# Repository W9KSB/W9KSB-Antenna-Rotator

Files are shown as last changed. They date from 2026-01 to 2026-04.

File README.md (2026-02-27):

# 🚀 Introducing the W9KSB Antenna Rotator

Movement Demo (https://www.youtube.com/watch?v=zZoIDCE3QLc)

(Video Above, Click to Play)

## About This Project (Overview)

This project is not a polished commercial product. It is a real-world, homebrew build that grew out of practical needs, experimentation, and a lot of tinkering. This project is provided for educational and hobby purposes only. Use at your own risk. I am not responsible for any damage resulting from construction or use.

The W9KSB Antenna Rotator exists because I wanted a reliable way to automate satellite tracking and reception from home without expensive commercial hardware. Along the way, the project evolved through trial, error, discussion, and learning — exactly how most good DIY projects do.

Everything here is shared **as-is**.  
There are **no warranties, guarantees, or promises of fitness** for any particular purpose.  
Hardware, software, and configurations may change over time, and what works in my environment may require adjustment in yours.

This GitHub repository hosts the bulk of the project, while my website provides detailed narrative posts, explanations, photos, and updates:

👉 https://www.w9ksb.com/

## Intent and Philosophy

- Document the build honestly — including decisions, tradeoffs, and limitations  
- Provide a clear starting point for others  
- Encourage experimentation, modification, and improvement  
- Share openly with the ham radio, SDR, and maker communities  

This is an off‑hours hobby project.  
Support is not guaranteed, and responses may be slow.  
Pull requests and respectful discussion are always welcome.

*(Disclaimer: This all needs updates I’m sure and I will be making many more edits. This is the literal first iteration of all of this, but I welcome feedback!)*

Main Rotator Image

Satellite passes are short. Winter is cold. Holding a heavy Yagi pointed at the sky for 12–15 minutes while trying to decode SSTV or weather images gets old fast.

This rotator was built to solve exactly that.

This project is a fully DIY AZ/EL antenna rotator powered by a Raspberry Pi 5, designed to integrate well with satellite reception and SSTV decoding workflows. The Pi runs everything — including SDR processing — so you can place the rotator outside, and the only thing entering the house is a short SMA cable.

Everything runs headless on a Pi 5 and integrates with:

- **Gpredict**
- **SatDump**
- **Hamlib rotctld**
- **RTL-SDR (optional)**

It can also run **SSTV decoding**, **NOAA/Meteor weather imaging**, and other tasks directly onboard.

---

# 🎯 Goals

- Fully automate satellite tracking
- Avoid holding a Yagi in freezing weather
- Decode signals while the rotator tracks passes automatically
- Keep the software modular and simple
- Use off-the-shelf parts wherever possible
- Document the entire build so others can replicate or improve it

---

# 🧰 Hardware Overview

## Core Components

- Raspberry Pi 5  
- Adafruit DC & Stepper Motor HAT  
- Two worm-gear DC motors (AZ + EL)  
- AS5600 absolute magnetic encoders  
- PETG 3D-printed body  
- Tripod mount  
- Optional RTL-SDR v4 for on-board reception  

### Wiring Diagram

Wiring Diagram

Encoders:
- One on hardware I²C bus 1  
- One on software I²C bus 3 via bit-banged GPIO  

Motors:
- Driven by Motor HAT  
- Powered by a linear 12V supply  
- Pi is powered by a buck converter  

---

# 🧬 Software Overview

The software consists of several Python modules:

| File | Purpose |
|---|---|
| **hamlib_server.py** | TCP server compatible with Hamlib/rotctld |
| **controller.py** | Brain of system — control loop, limits, homing |
| **movement.py** | Motor control via Motor HAT |
| **position.py** | AS5600 encoder interface |
| **config.py** | Central configuration file |
| **rotator_cal.json** | Stores calibration offsets |
| **manual.py** | Manual testing & jogging tool |

---

# 📸 Build Photos 

### Tripod Mount





### Rotator Body

Top

### Elevation Assembly

EL Hub
EL Side

### Bottom Access

Bottom

---

# 🛒 Parts List

## Core Electronics

| Product | Qty | Price | Link |
|---|-----|---|---|
| Raspberry Pi 5 | 1 | $91.00 | https://amzn.to/4rhhwjt |
| Adafruit Motor HAT | 1 | $29.79 | https://amzn.to/4t51I58 |
| Pin headers | 1 | $3.99 | https://amzn.to/4sYME8Z |
| AS5600 Encoders (4pk) | 1 | $9.99 | https://amzn.to/46frJ7J |
| Jumper wires | 1 | $6.98 | https://amzn.to/3O4QMnJ |

## Motors & Mechanics

| Product | Qty | Price | Link |
|---|-----|---|---|
| Worm gear motors (12v, 6rpm) | 2 | $9.37 | https://s.click.aliexpress.com/e/_mtrPuZF |
| Hyper Hub 1310 (6mm) | 2 | $7.99 | https://www.servocity.com/1310-series-hyper-hub-6mm-d-bore/ |
| Roller bearing | 1 | $7.98 | https://amzn.to/4r6E8D8 |
| Heat-set inserts | 1 | $15.99 | https://amzn.to/460NZ5c |
| M3 screws | 1 | $6.99 | https://amzn.to/4r5rLHe |

## Structural

| Product | Qty | Price | Link |
|---|-----|---|---|
| Tripod stand | 1 | $37.99 | https://amzn.to/4t0KGF3 |
| PETG filament | 2 | $14.43 | https://amzn.to/4bfPoIE |
| Baseball donut weight | 1–2 | $7.99 | https://amzn.to/4bmx7JI |

## Power & Wiring

| Product | Qty | Price | Link |
|---|-----|---|---|
| Linear PSU | 1 | $20 | https://amzn.to/49Xoov6 |
| DC pigtail | 1 | $8.99 | https://amzn.to/4bp9bpf |
| 12→5V buck | 1 | $9.59 | https://amzn.to/3ZuMDfl |
| 12V buck | 1 | $7.99 | https://amzn.to/49IAQjy |
| 28 AWG wire | 1 | $5.99 | https://amzn.to/3NwWkYa |

## Optional Onboard SDR

| Product | Qty | Price | Link |
|---|-----|---|---|
| RTL-SDR v4 | 1 | $39.99 | https://amzn.to/4k0bTU7 |
| SMA cable | 1 | $6.99 | https://amzn.to/45tG7sN |
| SMA bulkhead | 1 | $5.98 | https://amzn.to/49TQMhJ |

*These are the parts I ordered and used. Links below are affiliate links and I may earn a small commission on the sale at no additional cost to you.*
---

# 🧠 Software Architecture Deep Dive

## 📡 hamlib_server.py

- Implements TCP rotctld protocol  
- Talks to Gpredict & SatDump  
- On disconnect → returns AZ & EL to home  

## 🧮 controller.py

Handles:

- Control loop  
- Shortest-path AZ logic  
- Elevation limit enforcement  
- Homing  
- Arrival detection  

## ⚙ movement.py

- Motor HAT interface  
- Speed control  
- Direction handling  

## 🧭 position.py

- Reads AS5600 encoders  
- Bus 1 (hardware) + Bus 3 (bit‑banged)  
- Converts raw readings into degrees  

## 📝 config.py

- Motor speeds  
- Pins  
- I²C bus mappings  
- Limits  
- Thresholds  

## 🎯 rotator_cal.json

Stores offsets:

- **Elevation offset** is usually the only one you need  
- **Azimuth home** auto-sets at startup  
- AZ offset still supported for customization (v1 feature)  

## 🎛 manual.py

A simple tool for:

- Motor jogging  
- Testing direction  
- Verifying encoders  
- Manual positioning  

---

# 🏃 Running the Code

## Install prerequisites

```bash
sudo apt update && sudo apt upgrade -y
sudo apt install -y python3 python3-pip git i2c-tools adafruit-circuitpython-motorkit
```

## Enable I²C

```bash
sudo raspi-config
```

Enable I²C → Reboot.

## Enable Bit-Banged I²C (Bus 3)

Edit:

```bash
sudo nano /boot/config.txt
```

Add:

```
dtoverlay=i2c-gpio,bus=3,i2c_gpio_sda=24,i2c_gpio_scl=25
```

Reboot.

---

## Clone the repo

```bash
git clone https://github.com/W9KSB/W9KSB-Antenna-Rotator.git
cd W9KSB-Antenna-Rotator
```

---

## Run manually

```bash
sudo python3 -u hamlib_server.py
```

---

## Install as system service

Create:

```bash
sudo nano /etc/systemd/system/antenna-rotator.service
```

Paste:

```ini
[Unit]
Description=W9KSB Antenna Rotator Server
After=network.target

[Service]
ExecStart=/usr/bin/python3 -u /home/pi/W9KSB-Antenna-Rotator/hamlib_server.py
WorkingDirectory=/home/pi/W9KSB-Antenna-Rotator
StandardOutput=inherit
StandardError=inherit
Restart=always
User=root

[Install]
WantedBy=multi-user.target
```

Enable:

```bash
sudo systemctl daemon-reload
sudo systemctl enable antenna-rotator.service
sudo systemctl start antenna-rotator.service
```

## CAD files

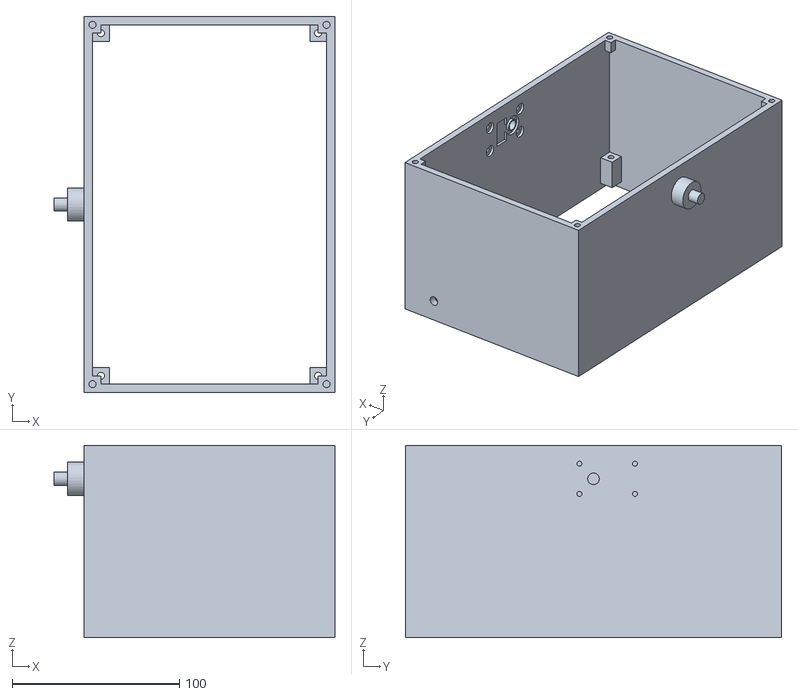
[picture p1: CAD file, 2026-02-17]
STL Files/Main Body.stl
168.0 x 225.0 x 115.0

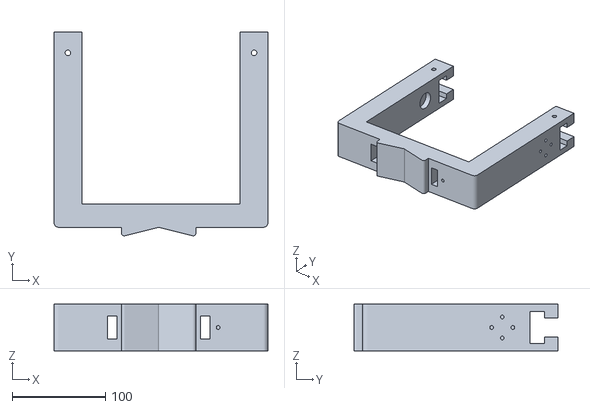
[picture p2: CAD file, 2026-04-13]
STL Files/Swing Arm With Antenna Mount Hole.stl
230.0 x 218.9 x 50.0

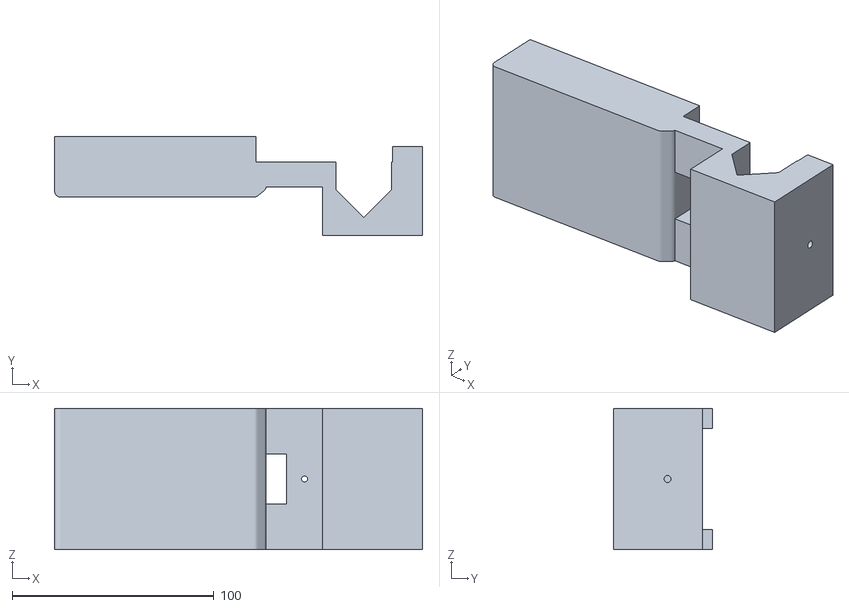
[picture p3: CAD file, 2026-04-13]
STL Files/Antenna Offset Mount - 45 Rotated.stl
182.5 x 49.0 x 70.0

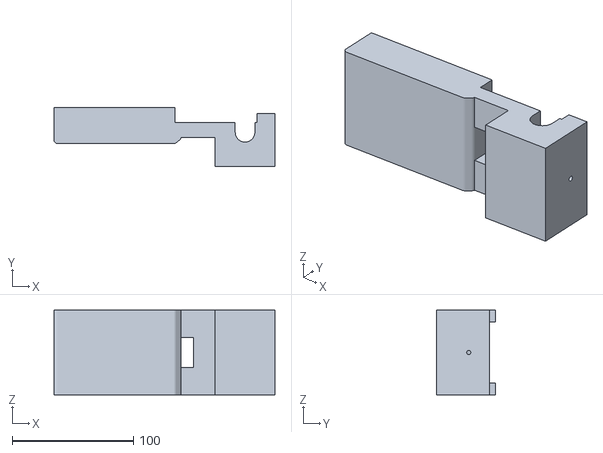
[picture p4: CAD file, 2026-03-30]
STL Files/ARRL Antenna Offset Mount.stl
182.5 x 49.0 x 70.0

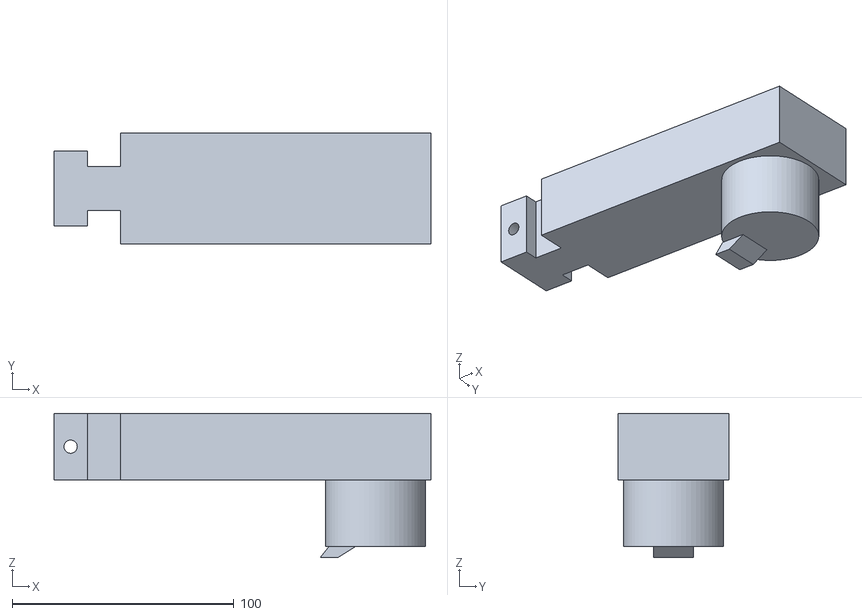
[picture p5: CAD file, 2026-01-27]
STL Files/Counterbalance Arm.stl
170.0 x 50.0 x 65.0

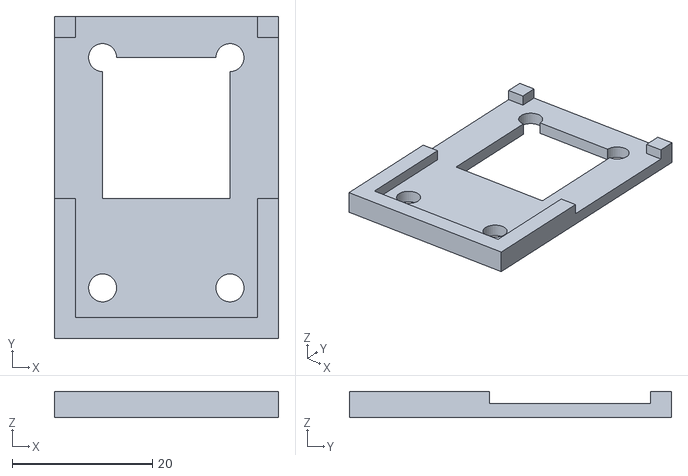
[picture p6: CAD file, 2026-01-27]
STL Files/Encoder Lid.stl
32.0 x 46.0 x 3.75

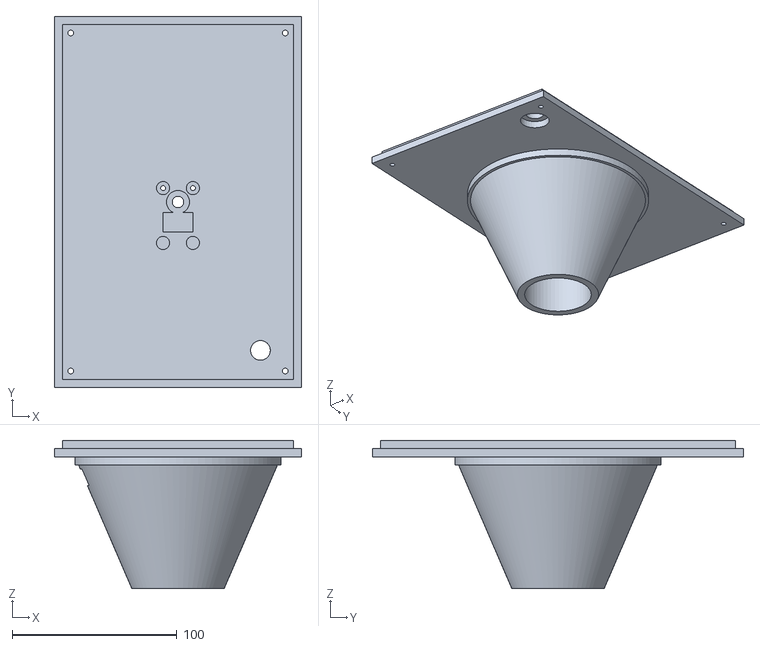
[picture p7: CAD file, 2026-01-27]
STL Files/Tripod Base Plate.stl
150.0 x 225.0 x 90.0

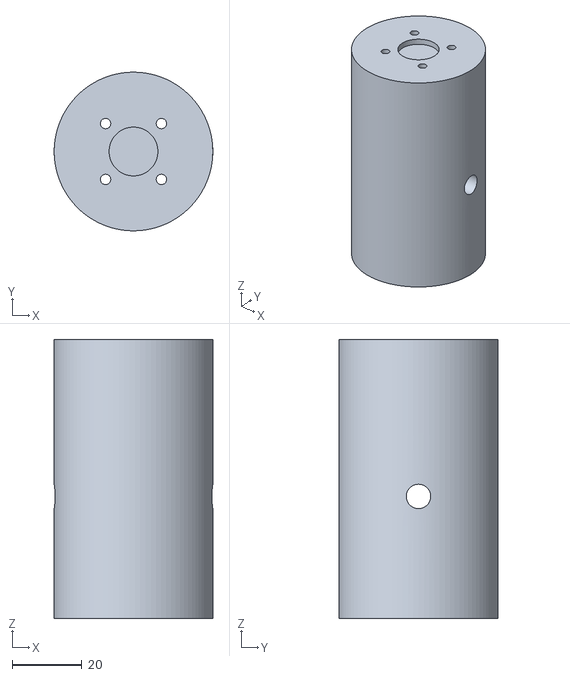
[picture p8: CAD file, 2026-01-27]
STL Files/Tripod Mount.stl
45.5 x 45.5 x 80.0

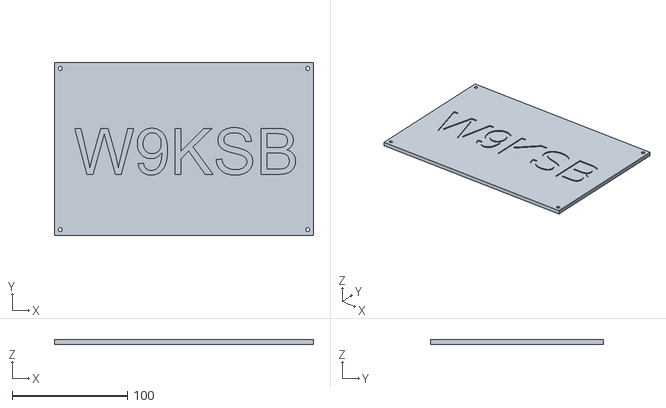
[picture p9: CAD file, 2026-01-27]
STL Files/Top Body Lid.stl
225.0 x 150.0 x 4.00

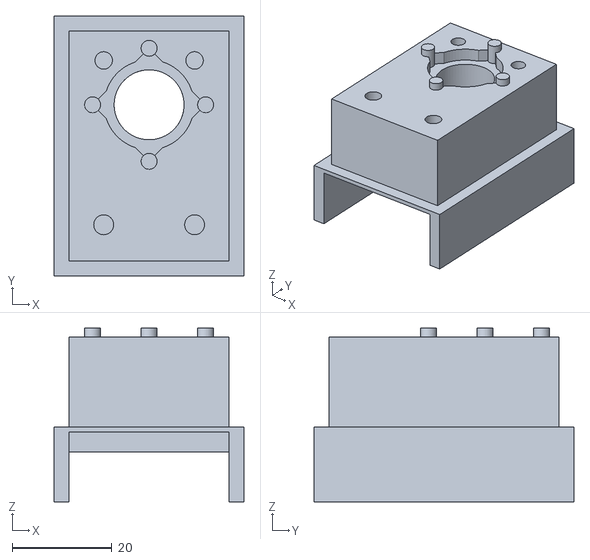
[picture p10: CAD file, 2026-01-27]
STL Files/Encoder Mount.stl
38.0 x 52.0 x 34.8

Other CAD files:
STL Files/3-4in Square Tube Antenna Offset Mount.stl
STL Files/Swing Arm - Adjusted for Counterbalance Arms.stl

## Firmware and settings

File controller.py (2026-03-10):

# controller.py
import time
import threading
import atexit

import config
import position
import movement

from Adafruit_MotorHAT import Adafruit_MotorHAT


def clamp(x, lo, hi):
    return max(lo, min(hi, float(x)))


class RotatorController:
    """
    Owns hardware and runs a background control loop.
    Exposes:
      - set_target(az_deg, el_deg)
      - get_position() -> (az_deg, el_deg)
      - stop()
    """

    def __init__(self, debug=False):
        self.debug = debug

        # Calibration
        self.cal = config.load_cal()

        # Motors
        self.mh = movement.init_motorhat()
        self.motor_az = self.mh.getMotor(1)
        self.motor_el = self.mh.getMotor(2)

        # Encoders
        self.enc_az = position.AS5600(config.ENCODER1_BUS, name="E1")
        self.enc_el = position.AS5600(config.ENCODER2_BUS, name="E2")
        self.az_tracker = position.UnwrappedAngle(self.enc_az)

        # State
        self._lock = threading.Lock()
        self._target_az = None  # physical 0..360
        self._target_el = None  # physical 0..90
        self._stop_requested = False

        self._cur_az_phys = 0.0
        self._cur_el_phys = 0.0
        self._cur_el_raw = 0.0  # raw AS5600 degrees (0..360)

        # Arrival reporting (print once per target)
        self._arrived_reported = False
        self._last_arrival_target = None  # (az, el)

        self._thread = None
        self._running = False

        # ----------------------------
        # EL control: breakaway search + approach slow + stall re-kick
        # ----------------------------
        self._el_dir_change_settle_s = float(getattr(config, "EL_DIR_CHANGE_SETTLE_S", 0.25))

        # Movement detection (raw degrees)
        self._el_move_thresh_deg = float(getattr(config, "EL_MOVE_THRESH_DEG", 0.25))
        self._el_move_window_s = float(getattr(config, "EL_MOVE_WINDOW_S", 0.30))

        # Stall detection (no meaningful movement while commanding)
        self._el_stall_time_s = float(getattr(config, "EL_STALL_TIME_S", 0.45))

        # Breakaway search (UP)
        self._el_up_bk_start = int(getattr(config, "EL_UP_BREAKAWAY_START_SPEED", 150))
        self._el_up_bk_step = int(getattr(config, "EL_UP_BREAKAWAY_STEP_SPEED", 25))
        self._el_up_bk_max = int(getattr(config, "EL_UP_BREAKAWAY_MAX_SPEED", 255))
        self._el_up_bk_interval_s = float(getattr(config, "EL_UP_BREAKAWAY_INTERVAL_S", 0.30))

        # Breakaway search (DOWN)
        self._el_down_bk_start = int(getattr(config, "EL_DOWN_BREAKAWAY_START_SPEED", 150))
        self._el_down_bk_step = int(getattr(config, "EL_DOWN_BREAKAWAY_STEP_SPEED", 25))
        self._el_down_bk_max = int(getattr(config, "EL_DOWN_BREAKAWAY_MAX_SPEED", 255))
        self._el_down_bk_interval_s = float(getattr(config, "EL_DOWN_BREAKAWAY_INTERVAL_S", 0.30))

        # Approach/creep windows
        self._el_approach_window_deg = float(getattr(config, "EL_APPROACH_WINDOW_DEG", 8.0))
        self._el_creep_window_deg = float(getattr(config, "EL_CREEP_WINDOW_DEG", 2.5))

        # Fixed approach/creep speeds
        self._el_approach_speed = int(getattr(config, "EL_APPROACH_SPEED", 120))
        self._el_creep_speed = int(getattr(config, "EL_CREEP_SPEED", 80))

        # UP travel uses your existing schedule (already in config)
        self._el_up_break_1 = float(getattr(config, "EL_UP_BREAK_1_DEG", 25.0))
        self._el_up_break_2 = float(getattr(config, "EL_UP_BREAK_2_DEG", 45.0))
        self._el_up_speed_0_25 = int(getattr(config, "EL_UP_SPEED_0_25", 250))
        self._el_up_speed_25_45 = int(getattr(config, "EL_UP_SPEED_25_45", 200))
        self._el_up_speed_45_max = int(getattr(config, "EL_UP_SPEED_45_MAX", 125))

        # DOWN travel base (used after breakaway, before approach windows)
        # (You can set this in config later; default keeps it strong but not max.)
        self._el_down_travel_speed = int(getattr(config, "EL_DOWN_TRAVEL_SPEED", 200))

        # Internal EL runtime
        self._el_state = "IDLE"   # IDLE, UP_BREAKAWAY, DOWN_BREAKAWAY, RUN
        self._el_last_dir = 0     # -1, 0, +1
        self._el_cmd_speed = 0
        self._el_next_step_ts = 0.0

        # Movement/stall bookkeeping
        self._el_last_move_raw = None
        self._el_last_move_ts = None
        self._el_stall_start_ts = None

        atexit.register(self.shutdown)

        # Prime readings + auto-zero AZ session-only
        try:
            _ = position.stable_read_unwrapped(self.az_tracker, seconds=0.25)
            _ = position.stable_read_wrapped(self.enc_el, seconds=0.25)

            cur_az_unwrapped = position.stable_read_unwrapped(self.az_tracker, seconds=0.25)
            self.cal["az_offset_deg"] = cur_az_unwrapped % 360.0
            print(f"[AZ] Auto-zero on startup: az_offset_deg={self.cal['az_offset_deg']:.6f}", flush=True)

            self._update_current_position()
        except Exception:
            pass

    # ---------------------------
    # Public API
    # ---------------------------

    def start(self):
        if self._thread and self._thread.is_alive():
            return
        self._running = True
        self._thread = threading.Thread(target=self._loop, daemon=True)
        self._thread.start()

    def shutdown(self):
        self._running = False
        try:
            self.stop()
        except Exception:
            pass

    def stop(self):
        with self._lock:
            self._stop_requested = True
            self._target_az = None
            self._target_el = None
            self._arrived_reported = False
            self._last_arrival_target = None

        self._el_reset()
        movement.stop_motor(self.motor_az)
        movement.stop_motor(self.motor_el)

    def set_target(self, az_deg, el_deg):
        az = float(az_deg) % 360.0
        el = clamp(el_deg, config.EL_MIN_DEG, config.EL_MAX_DEG)
        with self._lock:
            self._target_az = az
            self._target_el = el
            self._stop_requested = False
            self._arrived_reported = False
            self._last_arrival_target = (az, el)

    def get_position(self):
        with self._lock:
            return (float(self._cur_az_phys), float(self._cur_el_phys))

    def set_az_home_here(self):
        cur_unwrapped = position.stable_read_unwrapped(self.az_tracker, seconds=0.25)
        self.cal["az_offset_deg"] = cur_unwrapped % 360.0
        config.save_cal(self.cal)

    def set_el_zero_here(self):
        cur_raw = position.stable_read_wrapped(self.enc_el, seconds=0.25)
        self.cal["el_offset_deg"] = cur_raw % 360.0
        config.save_cal(self.cal)

    # ---------------------------
    # Internals
    # ---------------------------

    def _log(self, msg: str):
        if self.debug:
            print(msg, flush=True)

    def _motor_el_set(self, signed_dir: int, speed_0_255: int):
        if signed_dir == 0 or speed_0_255 <= 0:
            try:
                self.motor_el.setSpeed(0)
            except Exception:
                pass
            self.motor_el.run(Adafruit_MotorHAT.RELEASE)
            return

        if (signed_dir * int(config.M2_FORWARD_SIGN)) > 0:
            self.motor_el.run(Adafruit_MotorHAT.FORWARD)
        else:
            self.motor_el.run(Adafruit_MotorHAT.BACKWARD)

        self.motor_el.setSpeed(int(clamp(speed_0_255, 0, 255)))

    def _wrap_delta_deg(self, cur_raw: float, prev_raw: float) -> float:
        return (cur_raw - prev_raw + 180.0) % 360.0 - 180.0

    def _el_reset(self):
        self._el_state = "IDLE"
        self._el_last_dir = 0
        self._el_cmd_speed = 0
        self._el_next_step_ts = 0.0

        self._el_last_move_raw = None
        self._el_last_move_ts = None
        self._el_stall_start_ts = None

    def _el_mark_move(self, cur_raw: float):
        self._el_last_move_raw = cur_raw
        self._el_last_move_ts = time.time()
        self._el_stall_start_ts = None

    def _el_moved_recently(self, cur_raw: float) -> bool:
        now = time.time()
        if self._el_last_move_raw is None or self._el_last_move_ts is None:
            self._el_last_move_raw = cur_raw
            self._el_last_move_ts = now
            return False

        if (now - self._el_last_move_ts) < 0.01:
            return False

        if (now - self._el_last_move_ts) >= self._el_move_window_s:
            d = self._wrap_delta_deg(cur_raw, self._el_last_move_raw)
            if abs(d) >= self._el_move_thresh_deg:
                self._el_mark_move(cur_raw)
                return True
            else:
                # refresh window anchor (prevents old anchor from causing weird deltas)
                self._el_last_move_raw = cur_raw
                self._el_last_move_ts = now
                return False

        return False

    def _el_stalled(self) -> bool:
        now = time.time()
        if self._el_stall_start_ts is None:
            self._el_stall_start_ts = now
            return False
        return (now - self._el_stall_start_ts) >= self._el_stall_time_s

    def _el_up_schedule_speed(self, cur_el_phys: float) -> int:
        if cur_el_phys < self._el_up_break_1:
            return self._el_up_speed_0_25
        if cur_el_phys < self._el_up_break_2:
            return self._el_up_speed_25_45
        return self._el_up_speed_45_max

    def _el_enter_breakaway(self, desired_dir: int, cur_raw: float):
        now = time.time()
        if desired_dir > 0:
            self._el_state = "UP_BREAKAWAY"
            self._el_cmd_speed = int(clamp(self._el_up_bk_start, 0, 255))
            self._el_next_step_ts = now + self._el_up_bk_interval_s
        else:
            self._el_state = "DOWN_BREAKAWAY"
            self._el_cmd_speed = int(clamp(self._el_down_bk_start, 0, 255))
            self._el_next_step_ts = now + self._el_down_bk_interval_s

        self._el_last_move_raw = cur_raw
        self._el_last_move_ts = now
        self._el_stall_start_ts = None

        if self.debug:
            self._log(f"[EL] enter {self._el_state} start_speed={self._el_cmd_speed}")

    def _el_tick(self, el_err_deg: float, cur_el_phys: float, cur_raw: float) -> bool:
        # deadband
        if abs(el_err_deg) <= config.DEADBAND_DEG:
            self._motor_el_set(0, 0)
            self._el_reset()
            return True

        desired_dir = +1 if el_err_deg > 0 else -1

        # direction-change settle
        if desired_dir != 0 and self._el_last_dir != 0 and desired_dir != self._el_last_dir:
            if self.debug:
                self._log(f"[EL] dir change {self._el_last_dir} -> {desired_dir}: STOP+SETTLE {self._el_dir_change_settle_s:.2f}s")
            self._motor_el_set(0, 0)
            movement.stop_motor(self.motor_el)
            self._el_reset()
            time.sleep(self._el_dir_change_settle_s)

        # Start breakaway if idle or direction changed / state mismatched
        if self._el_state == "IDLE":
            self._el_enter_breakaway(desired_dir, cur_raw)

        if (desired_dir > 0 and self._el_state == "DOWN_BREAKAWAY") or (desired_dir < 0 and self._el_state == "UP_BREAKAWAY"):
            self._el_enter_breakaway(desired_dir, cur_raw)

        now = time.time()

        # Determine requested speed for approach/creep when RUN
        def approach_speed() -> int:
            aerr = abs(el_err_deg)
            if aerr <= self._el_creep_window_deg:
                return int(clamp(self._el_creep_speed, 0, 255))
            if aerr <= self._el_approach_window_deg:
                return int(clamp(self._el_approach_speed, 0, 255))
            return -1  # not in approach/creep

        # BREAKAWAY modes: step until movement is detected
        if self._el_state in ("UP_BREAKAWAY", "DOWN_BREAKAWAY"):
            # command current breakaway speed
            self._motor_el_set(desired_dir, self._el_cmd_speed)

            moved = self._el_moved_recently(cur_raw)
            if moved:
                # movement detected -> RUN
                self._el_state = "RUN"
                self._el_stall_start_ts = None
                if self.debug:
                    self._log(f"[EL] movement detected -> RUN (bk_speed={self._el_cmd_speed})")
                return True

            # no movement yet: stall timer
            if self._el_stall_start_ts is None:
                self._el_stall_start_ts = now

            # step-up timing
            interval = self._el_up_bk_interval_s if desired_dir > 0 else self._el_down_bk_interval_s
            step = self._el_up_bk_step if desired_dir > 0 else self._el_down_bk_step
            vmax = self._el_up_bk_max if desired_dir > 0 else self._el_down_bk_max

            if now >= self._el_next_step_ts:
                old = self._el_cmd_speed
                self._el_cmd_speed = int(clamp(old + step, 0, vmax))
                self._el_next_step_ts = now + interval
                if self.debug:
                    self._log(f"[EL] breakaway step {old}->{self._el_cmd_speed} (max={vmax})")

            return True

        # RUN mode: choose speed based on approach/creep, but if we stall, re-enter breakaway
        if self._el_state == "RUN":
            sp = approach_speed()

            if sp < 0:
                # not in approach window: travel speed
                if desired_dir > 0:
                    sp = int(clamp(self._el_up_schedule_speed(cur_el_phys), 0, 255))
                else:
                    sp = int(clamp(self._el_down_travel_speed, 0, 255))

            self._motor_el_set(desired_dir, sp)

            # update movement check; if we see movement, clear stall timer
            if self._el_moved_recently(cur_raw):
                return True

            # no movement: start/advance stall timer, then re-kick into breakaway
            if self._el_stall_start_ts is None:
                self._el_stall_start_ts = now
                return True

            if self._el_stalled():
                # re-enter breakaway, but seed start speed from the speed we were using
                if desired_dir > 0:
                    self._el_up_bk_start = int(min(255, max(self._el_up_bk_start, sp)))
                else:
                    self._el_down_bk_start = int(min(255, max(self._el_down_bk_start, sp)))

                if self.debug:
                    self._log(f"[EL] stall in RUN at sp={sp} -> re-breakaway (dir={desired_dir})")

                self._el_enter_breakaway(desired_dir, cur_raw)
                return True

            return True

        return False

    def _update_current_position(self):
        # AZ
        az_unwrapped = self.az_tracker.read()
        az_phys = position.az_unwrapped_to_physical(az_unwrapped, self.cal["az_offset_deg"])

        # EL
        el_raw = self.enc_el.read_degrees_filtered()
        el_phys = position.el_raw_to_physical(el_raw, self.cal["el_offset_deg"])

        with self._lock:
            self._cur_az_phys = az_phys % 360.0
            self._cur_el_phys = el_phys
            self._cur_el_raw = float(el_raw)

    def _loop(self):
        period = 1.0 / float(config.CONTROL_HZ)

        while self._running:
            t0 = time.time()
            try:
                self._update_current_position()

                with self._lock:
                    target_az = self._target_az
                    target_el = self._target_el
                    stop_req = self._stop_requested
                    arrived_reported = self._arrived_reported

                if stop_req or (target_az is None and target_el is None):
                    self._el_reset()
                    movement.stop_motor(self.motor_az)
                    movement.stop_motor(self.motor_el)
                else:
                    cur_az_unwrapped = self.az_tracker.unwrapped
                    cur_az_phys, cur_el_phys = self.get_position()
                    cur_el_raw = float(self._cur_el_raw)

                    tgt_el = clamp(target_el, config.EL_MIN_DEG, config.EL_MAX_DEG)
                    el_err = tgt_el - cur_el_phys

                    tgt_unwrapped = position.nearest_unwrapped_target(
                        current_unwrapped=cur_az_unwrapped,
                        target_az_phys_deg=target_az,
                        az_offset_deg=self.cal["az_offset_deg"],
                    )
                    az_err = tgt_unwrapped - cur_az_unwrapped

                    az_done = abs(az_err) <= config.DEADBAND_DEG
                    el_done = abs(el_err) <= config.DEADBAND_DEG

                    if az_done and el_done:
                        self._el_reset()
                        movement.stop_motor(self.motor_az)
                        movement.stop_motor(self.motor_el)

                        if not arrived_reported:
                            with self._lock:
                                if (self._target_az is not None) and (self._target_el is not None) and (not self._arrived_reported):
                                    az_print = self._cur_az_phys
                                    el_print = self._cur_el_phys
                                    tgt = self._last_arrival_target
                                    self._arrived_reported = True

                                    if tgt is not None:
                                        print(
                                            f"[ARRIVED] AZ={az_print:7.2f}°  EL={el_print:6.2f}°   (target AZ={tgt[0]:.2f} EL={tgt[1]:.2f})",
                                            flush=True
                                        )
                                    else:
                                        print(f"[ARRIVED] AZ={az_print:7.2f}°  EL={el_print:6.2f}°", flush=True)
                    else:
                        if arrived_reported:
                            with self._lock:
                                self._arrived_reported = False

                        # EL safety clamp
                        if (cur_el_phys <= config.EL_MIN_DEG + config.DEADBAND_DEG) and (el_err < 0):
                            self._el_reset()
                            movement.stop_motor(self.motor_el)
                            self._el_last_dir = 0
                        elif (cur_el_phys >= config.EL_MAX_DEG - config.DEADBAND_DEG) and (el_err > 0):
                            self._el_reset()
                            movement.stop_motor(self.motor_el)
                            self._el_last_dir = 0
                        else:
                            handled = self._el_tick(el_err, cur_el_phys, cur_el_raw)
                            if not handled:
                                # fallback to original behavior
                                self._el_reset()
                                movement.drive_toward_error(self.motor_el, config.M2_FORWARD_SIGN, el_err)

                            # record last dir for settle logic
                            if el_err > config.DEADBAND_DEG:
                                self._el_last_dir = +1
                            elif el_err < -config.DEADBAND_DEG:
                                self._el_last_dir = -1
                            else:
                                self._el_last_dir = 0

                        # AZ unchanged
                        movement.drive_toward_error(self.motor_az, config.M1_FORWARD_SIGN, az_err)

            except Exception:
                try:
                    self._el_reset()
                    movement.stop_motor(self.motor_az)
                    movement.stop_motor(self.motor_el)
                except Exception:
                    pass

            dt = time.time() - t0
            sleep_for = period - dt
            if sleep_for > 0:
                time.sleep(sleep_for)


if __name__ == "__main__":
    import argparse

    p = argparse.ArgumentParser(description="Rotator controller core (no Hamlib server).")
    p.add_argument("--status", action="store_true")
    p.add_argument("--az", type=float)
    p.add_argument("--el", type=float)
    p.add_argument("--az_home_here", action="store_true")
    p.add_argument("--el_zero_here", action="store_true")
    p.add_argument("--debug", action="store_true")
    args = p.parse_args()

    rc = RotatorController(debug=args.debug)
    rc.start()

    if args.az_home_here:
        rc.set_az_home_here()
        print("AZ home saved.")
        raise SystemExit(0)

    if args.el_zero_here:
        rc.set_el_zero_here()
        print("EL zero saved.")
        raise SystemExit(0)

    if args.status:
        time.sleep(0.3)
        az, el = rc.get_position()
        print(f"AZ: {az:.2f}° (offset {rc.cal['az_offset_deg']:.2f})   EL: {el:.2f}° (offset {rc.cal['el_offset_deg']:.2f})")
        raise SystemExit(0)

    if args.az is not None or args.el is not None:
        rc.set_target(
            args.az if args.az is not None else 0.0,
            args.el if args.el is not None else 0.0
        )
        while True:
            time.sleep(1.0)

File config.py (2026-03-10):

# config.py
import json
import os

# ----------------------------
# Hardware mapping
# ----------------------------
AS5600_ADDR = 0x36

ENCODER1_BUS = 1   # Encoder1 -> Motor1 (Az)
ENCODER2_BUS = 3   # Encoder2 -> Motor2 (El)

MOTOR_HAT_ADDR = 0x60
MOTOR_HAT_BUS = 1

# Direction mapping from your tests:
# +1 means: commanding FORWARD causes encoder angle to increase
M1_FORWARD_SIGN = -1   # Motor1 FORWARD decreases encoder
M2_FORWARD_SIGN = +1   # Motor2 FORWARD increases encoder

# ----------------------------
# Elevation constraints (physical)
# ----------------------------
EL_MIN_DEG = 0.0
EL_MAX_DEG = 90.0

# ----------------------------
# Control tuning
# ----------------------------
CONTROL_HZ = 15.0                  # controller loop rate
READ_INTERVAL = 0.05               # used for debug-style loops (not required by control loop)

SAMPLES_PER_READ = 5
I2C_RETRIES = 3
MAX_JUMP_DEG = 25.0

# These are used by movement.py for AZ and as general fallbacks.
FAST_SPEED  = 170
SLOW_SPEED  = 125
CREEP_SPEED = 100

SLOW_WINDOW_DEG  = 10.0
CREEP_WINDOW_DEG = 2.5
DEADBAND_DEG     = 1

# ----------------------------
# Elevation UP travel schedule (used when not in approach/creep)
# ----------------------------
# Based on *current* elevation while moving UP
EL_UP_SPEED_0_25   = 250
EL_UP_SPEED_25_45  = 200
EL_UP_SPEED_45_MAX = 125

EL_UP_BREAK_1_DEG = 25.0
EL_UP_BREAK_2_DEG = 45.0

# ----------------------------
# Elevation DOWN travel speed (used when not in approach/creep)
# ----------------------------
# After breakaway is achieved, and while not near the target,
# DOWN uses this steady "travel" speed.
EL_DOWN_TRAVEL_SPEED = 200

# ----------------------------
# Elevation breakaway search + stall recovery (NEW controller behavior)
# ----------------------------
# Movement detection (encoder raw degrees). Must be above noise.
EL_MOVE_THRESH_DEG = 0.25
EL_MOVE_WINDOW_S   = 0.30

# If we are commanding motion but we do not detect movement long enough,
# we consider it stalled and re-enter breakaway search.
EL_STALL_TIME_S = 0.45

# Breakaway search (UP)
EL_UP_BREAKAWAY_START_SPEED    = 50
EL_UP_BREAKAWAY_STEP_SPEED     = 50
EL_UP_BREAKAWAY_MAX_SPEED      = 255
EL_UP_BREAKAWAY_INTERVAL_S     = 0.30

# Breakaway search (DOWN)
# Your testing showed ~200-210 breaks free at ~80° EL, so keep max flexible.
EL_DOWN_BREAKAWAY_START_SPEED  = 100
EL_DOWN_BREAKAWAY_STEP_SPEED   = 50
EL_DOWN_BREAKAWAY_MAX_SPEED    = 255
EL_DOWN_BREAKAWAY_INTERVAL_S   = 0.30

# ----------------------------
# Elevation approach / creep (smooth near target, but will re-kick if it stalls)
# ----------------------------
EL_APPROACH_WINDOW_DEG = 8.0
EL_CREEP_WINDOW_DEG    = 2.5

EL_APPROACH_SPEED      = 100
EL_CREEP_SPEED         = 60

# Optional: settle time when changing EL direction
EL_DIR_CHANGE_SETTLE_S = 0.25

# ----------------------------
# (Removed) old "max power zones" + governor settings
# ----------------------------
# These are NOT used by the new controller.py you just installed:
#   EL_UP_MAXZONE_*
#   EL_DOWN_MAXZONE_*
#   EL_DOWN_GOV_*
# You can re-add later if you decide to bring that behavior back.

# ----------------------------
# Calibration storage
# ----------------------------
CAL_FILE = "rotator_cal.json"


def load_cal():
    """
    Loads offsets from rotator_cal.json if present.
    Offsets are RAW wrapped degrees (0..360) that correspond to physical zero.
      az_offset_deg: raw E1 angle that equals AZ=0
      el_offset_deg: raw E2 angle that equals EL=0 (horizon)
    """
    cal = {
        "az_offset_deg": 0.0,
        "el_offset_deg": 0.0,
    }
    if os.path.exists(CAL_FILE):
        try:
            with open(CAL_FILE, "r") as f:
                cal.update(json.load(f))
        except Exception:
            pass
    return cal


def save_cal(cal):
    with open(CAL_FILE, "w") as f:
        json.dump(cal, f, indent=2, sort_keys=True)

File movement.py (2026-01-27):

# movement.py
from Adafruit_MotorHAT import Adafruit_MotorHAT
import Adafruit_GPIO.I2C as I2C

import config


class FixedBusI2C:
    """
    MotorHAT library workaround: provide get_i2c_device() and force busnum.
    """
    def __init__(self, busnum):
        self.busnum = busnum

    def get_i2c_device(self, address, **kwargs):
        return I2C.get_i2c_device(address, busnum=self.busnum, **kwargs)


def init_motorhat():
    mh_i2c = FixedBusI2C(config.MOTOR_HAT_BUS)
    mh = Adafruit_MotorHAT(addr=config.MOTOR_HAT_ADDR, i2c=mh_i2c)
    return mh


def motor_set_speed(motor, speed):
    motor.setSpeed(max(0, min(255, int(speed))))


def motor_dir_for_error(forward_sign, err_deg):
    """
    err_deg > 0 means we want encoder angle to increase.
    forward_sign says whether FORWARD increases (+1) or decreases (-1).
    """
    want_increase = err_deg > 0
    if want_increase:
        return Adafruit_MotorHAT.FORWARD if forward_sign == +1 else Adafruit_MotorHAT.BACKWARD
    else:
        return Adafruit_MotorHAT.BACKWARD if forward_sign == +1 else Adafruit_MotorHAT.FORWARD


def speed_for_error(abs_err):
    if abs_err <= config.CREEP_WINDOW_DEG:
        return config.CREEP_SPEED
    if abs_err <= config.SLOW_WINDOW_DEG:
        return config.SLOW_SPEED
    return config.FAST_SPEED


def drive_toward_error(motor, forward_sign, err_deg):
    """
    Non-blocking: for this tick, drive motor toward reducing err_deg.
    Returns True if "at target" (within deadband), else False.
    """
    if abs(err_deg) <= config.DEADBAND_DEG:
        motor.run(Adafruit_MotorHAT.RELEASE)
        return True

    spd = speed_for_error(abs(err_deg))
    direction = motor_dir_for_error(forward_sign, err_deg)
    motor_set_speed(motor, spd)
    motor.run(direction)
    return False


def stop_motor(motor):
    motor.run(Adafruit_MotorHAT.RELEASE)

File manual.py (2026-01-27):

# manual.py
# Keyboard jog control for your rotator.
#
# Controls:
#   A / D  : Azimuth jog (left/right)
#   W / S  : Elevation jog (up/down)
#   Space  : Stop all motors
#   P      : Print current AZ/EL
#   H      : Save AZ home here (AZ=0)
#   J      : Save EL zero here (EL=0 horizon)
#   Q      : Quit
#
# Notes:
# - Uses your existing libraries/config (config.py, position.py, movement.py).
# - Runs in the terminal. Requires sudo for I2C/motors like your other scripts.
# - This is a *jog* tool: motors move while a key is held (key repeat works too).
# - Elevation LIMITS are DISABLED in this manual tool (no 0..90 clamping).

import sys
import time
import atexit

from Adafruit_MotorHAT import Adafruit_MotorHAT

import config
import position
import movement


# ---------------------------
# Simple terminal key reading
# ---------------------------
def _getch():
    """
    Read a single keypress (non-blocking-ish by using raw mode).
    Works over SSH too.
    """
    import termios
    import tty
    import select

    fd = sys.stdin.fileno()
    old = termios.tcgetattr(fd)
    try:
        tty.setcbreak(fd)
        r, _, _ = select.select([sys.stdin], [], [], 0.05)
        if r:
            return sys.stdin.read(1)
        return None
    finally:
        termios.tcsetattr(fd, termios.TCSADRAIN, old)


def main():
    cal = config.load_cal()

    # Hardware init
    mh = movement.init_motorhat()
    motor_az = mh.getMotor(1)  # M1 = AZ
    motor_el = mh.getMotor(2)  # M2 = EL

    enc_az = position.AS5600(config.ENCODER1_BUS, name="E1")
    enc_el = position.AS5600(config.ENCODER2_BUS, name="E2")
    az_tracker = position.UnwrappedAngle(enc_az)

    # Prime stable reads (and reduce initial jitter)
    position.stable_read_unwrapped(az_tracker, seconds=0.3)
    position.stable_read_wrapped(enc_el, seconds=0.3)

    def stop_all():
        movement.stop_motor(motor_az)
        movement.stop_motor(motor_el)

    atexit.register(stop_all)

    def get_positions():
        # AZ physical is derived from unwrapped minus az_offset (wrapped 0..360)
        az_unwrapped = az_tracker.read()
        az_phys = position.az_unwrapped_to_physical(az_unwrapped, cal["az_offset_deg"]) % 360.0

        # EL physical is wrap_delta(raw, el_offset). For manual mode, we do NOT clamp.
        el_raw = enc_el.read_degrees_filtered()
        el_phys = position.el_raw_to_physical(el_raw, cal["el_offset_deg"])
        return az_phys, el_phys

    def print_positions(prefix="[POS]"):
        az, el = get_positions()
        print(
            f"{prefix} AZ={az:7.2f}°  EL={el:7.2f}°   "
            f"(az_off={cal['az_offset_deg']:.2f}  el_off={cal['el_offset_deg']:.2f})",
            flush=True
        )

    def save_az_home_here():
        # Want current physical AZ = 0 => az_offset = current raw wrapped (unwrapped % 360)
        cur_unwrapped = position.stable_read_unwrapped(az_tracker, seconds=0.25)
        cal["az_offset_deg"] = cur_unwrapped % 360.0
        config.save_cal(cal)
        print(f"[CAL] Saved AZ home here. az_offset_deg={cal['az_offset_deg']:.6f}", flush=True)

    def save_el_zero_here():
        # Want current physical EL = 0 => el_offset = current raw wrapped
        cur_raw = position.stable_read_wrapped(enc_el, seconds=0.25)
        cal["el_offset_deg"] = cur_raw % 360.0
        config.save_cal(cal)
        print(f"[CAL] Saved EL zero here. el_offset_deg={cal['el_offset_deg']:.6f}", flush=True)

    # Jog tuning
    JOG_SPEED_AZ = 120
    JOG_SPEED_EL = 120

    # Key repeat / command hold behavior
    HOLD_SEC = 0.20
    last_cmd_time = 0.0
    active_cmd = None  # one of: 'AZ_LEFT','AZ_RIGHT','EL_UP','EL_DOWN'

    print("\nManual jog control ready.\n")
    print("Controls:")
    print("  A/D : AZ jog")
    print("  W/S : EL jog")
    print("  Space: stop motors")
    print("  P : print positions")
    print("  H : save AZ home here (AZ=0)")
    print("  J : save EL zero here (EL=0)")
    print("  Q : quit\n")
    print("NOTE: Elevation limits are DISABLED in this manual tool.\n")
    print_positions(prefix="[START]")

    try:
        while True:
            k = _getch()
            now = time.time()

            if k:
                kk = k.lower()

                if kk == "q":
                    print("\n[QUIT] Exiting manual jog.", flush=True)
                    break

                if kk == " ":
                    active_cmd = None
                    stop_all()
                    print("[STOP] Motors released.", flush=True)
                    continue

                if kk == "p":
                    print_positions()
                    continue

                if kk == "h":
                    stop_all()
                    save_az_home_here()
                    print_positions(prefix="[POS]")
                    continue

                if kk == "j":
                    stop_all()
                    save_el_zero_here()
                    print_positions(prefix="[POS]")
                    continue
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

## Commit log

2026-02-02 Update README.md
    Added motor purchase link.
2026-02-06 Update config.py
    Added Variables for elevation tweaks. I made changes to the elevation increase functionality where stronger \ faster speeds are used when the elevation is low. I was getting motor whine and no movement when trying to lift an antenna from the home position small movements (due to the weight). Made it so there are faster movements for movements close to the home position and gradually slows as movements reach more vertical and weight isnt as much an issue.
    [config.py]
2026-02-06 Update controller.py
    Added elevation tweaks. I made changes to the elevation increase functionality where stronger \ faster speeds are used when the elevation is low. I was getting motor whine and no movement when trying to lift an antenna from the home position small movements (due to the weight). Made it so there are faster movements for movements close to the home position and gradually slows as movements reach more vertical and weight isnt as much an issue.
    [controller.py]
2026-02-17 Add files via upload
    Optional Antenna Mount for an offset position (not directly above the rotator). This is to be used in cases like the Arrow antenna where antenna is multi-band perhaps and elements are 90 degrees perpendicular to each other where there would be clearance issues with elements hitting the rotator when elevation is changed. Antenna sits very slightly on the side of the antenna boom mount.
    [3-4in Square Tube Antenna Offset Mount.stl]
2026-02-17 Add files via upload
    Printed with PETG and the hole was too close to the elevation motor shaft size, with a load, some rubbing was happening making a "fun" noise. I removed the noise by using dri-lube in my case, but I enlarged the hole a minimal amount for future builds.
    [Main Body.stl]
2026-03-10 Update config.py
    Updated to work with new controller file for better handling of heavy antennas.
2026-03-10 Update controller.py
    Optimized the method in which I was handling heavier antennas. Working great now.
2026-03-30 Add files via upload
    Per request, antenna mount, offset position for a side mount for the ARRL multiband antenna
    [ARRL Antenna Offset Mount.stl]
2026-04-13 Add files via upload
    Added a new swing arm version with an additional hole to be used with the antenna mounts to hold it on instead of the pipe clamp.
    [Swing Arm With Antenna Mount Hole.stl]
